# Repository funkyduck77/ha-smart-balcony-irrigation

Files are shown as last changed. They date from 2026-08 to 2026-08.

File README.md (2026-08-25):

# 🌱 Home Assistant Balkon-Bewässerungssystem

Ein intelligentes, vollautomatisiertes und ausfallsicheres Bewässerungssystem für den Balkon. Vollständig integriert in Home Assistant mit dynamischer Füllstandsberechnung, mehreren Fallback-Ebenen (Watchdogs) und individueller Gießlogik für bis zu 5 Pflanzen (Slots).

## 💡 Key Features
- **Brutto vs. Netto Füllstandsberechnung:** Striktes Trennen von physischem Wasser und nutzbarem Wasser (Totvolumen der Pumpe).
- **Hybrid-Steuerung:** Gießen nach Uhrzeit (oder Sonnenauf-/untergang) in Kombination mit echter Bodenfeuchte.
- **Untersetzer-Modus vs. Tröpfchen:** Intelligente Sperrzeiten nach dem Fluten des Untersetzers (inkl. Hitze-Bypass) oder Sickerpausen beim Gießen von oben.
- **Multi-Level Watchdogs:** Hardware-Trockenlaufschutz via aktiver Strommessung und dynamische Laufzeitlimits.
- **Smartes Logbuch:** Zeichnet jeden Gießvorgang inkl. Dauer, Verbrauch und Art (Manuell/Automatisch) auf.

---

## 📸 Screenshots & Dashboard

### Hauptansichten
*Das Responsive 2-Spalten-Layout auf dem Desktop.*
<br>
[Dashboard Hauptansicht](https://github.com/user-attachments/assets/e46ffc9e-1050-4b72-8b72-4a37b806c261)

*Die optimierte 1-Spalten-Ansicht für mobile Endgeräte.*
<br>
[Dashboard Mobile](https://github.com/user-attachments/assets/5ae38f84-7e9f-45ac-9b3f-b62c335ae683)

### Konfiguration
*Zentrale Konfiguration für Wasserfass und Watchdogs.*
<br>
[Globale Einstellungen](https://github.com/user-attachments/assets/2fc29b8b-f593-4bb9-b03f-c58f92324a54)

*Zentrale Vergabe der Pflanzennamen in den globalen Einstellungen.*
<br>
[Pflanzennamen Setup](https://github.com/user-attachments/assets/1ad855d4-3897-4641-916f-8dc4160eff52)

### Feinjustierung der Pflanzen
*Beispiel: Klassisches Gießen mit Start-/Zielwert und Sickerpausen.*
<br>
[Feinjustierung Tröpfchen](https://github.com/user-attachments/assets/3833a239-f6f6-4e24-8c0a-7977c8816305)

*Beispiel: Untersetzer-Modus mit langer Sperrzeit nach dem Fluten.*
<br>
[Feinjustierung Untersetzer](https://github.com/user-attachments/assets/ca4b359d-ce65-41ae-a133-8690ff3e2794)

*Steuerung nach Uhrzeit und das Notfall-Setup.*
<br>
[Uhrzeitsteuerung & Notfall](https://github.com/user-attachments/assets/7c919bb4-a890-4a9a-9201-73c406db67ec)

*Dynamische Steuerung nach Sonnenstand und das Notfall-Setup.*
<br>
[Sonnensteuerung & Notfall](https://github.com/user-attachments/assets/6598a505-8b60-41e8-8f59-561ecc60e1ed)

### Tools
*Fass befüllen oder Wasserverbrauch manuell korrigieren.*
<br>
[Manuelle Korrektur](https://github.com/user-attachments/assets/e38ff588-c6be-460b-87ec-2e6eee3abf9b)

### System
*Manuelle Kontrolle aller Hardware-Komponenten (Pumpe, Ventile & Trockenlaufschutz).*
<br>
[System-Übersicht](https://github.com/user-attachments/assets/c0530f64-9929-4684-b313-7d23d404d7c2)

### Historie
*Smartes Logbuch mit Historie über Dauer, Verbrauch und Liter pro Stunde (L/h).*
<br>
[Logbuch](https://github.com/user-attachments/assets/27954695-1dcf-47cf-ad8b-151f54cea6f6)

---

## 🛡️ Sicherheitskonzept (Die Watchdogs)

Da Wasserschäden auf Balkonen gelinde gesagt ungünstig sind und Pumpen nicht trockenlaufen oder gegen große Widerstände arbeiten dürfen, verfügt das System über fünf redundante Sicherheitsmechanismen. Fällt eine Ebene aus, greift sofort die nächste:

**1. Füllstandschutz (Software-Trockenlaufschutz)**
Das System berechnet kontinuierlich das verbleibende Wasser im Fass über Gießzeit und angegebenen Durchfluss. Erreicht dieser berechnete Wert das von dir in den globalen Einstellungen definierte "Totvolumen" (die Menge an Wasser, die nicht angesaugt werden kann, plus die Wasserverdrängung der Pumpe selbst), wird die Pumpe softwareseitig blockiert. Das verhindert, dass sie bei leerem Fass anläuft.

**2. Hardware-Trockenlaufschutz (Aktive Strommessung)**
Sollte der berechnete Wasserstand falsch sein (z. B. durch manuelle Entnahme mit der Gießkanne), greift diese physische Absicherung. Die smarte Steckdose überwacht den Stromverbrauch der Pumpe in Echtzeit. Zieht die Pumpe plötzlich weniger als 150 Watt Leistung, bedeutet das: Sie pumpt keinen Widerstand (Wasser) mehr, sondern zieht Luft. Das System blockiert die Pumpe innerhalb von Sekunden. 

**3. Dynamischer Laufzeit-Watchdog (Smartes Zeitlimit)**
Diese Funktion verhindert Überschwemmungen bei einem fehlerhaften Ablauf. Da das System die Ventile immer brav nacheinander gießt (Queued-Modus), prüft es bei jedem Start, welches Ventil gerade öffnet. Es nimmt die für genau diesen Slot geplante Gießdauer und addiert pauschal 2 Minuten als Sicherheitspuffer. Läuft die Pumpe bei diesem einen Durchgang unvorhergesehen länger als dieser errechnete Wert, kappt der Watchdog den Strom.

**4. Ghost-Prevention (Pumpen-Schutz)**
Wenn die Pumpe anspringt – sei es durch einen Glitch oder manuelles Schalten der Steckdose – ohne dass ein Ventil geöffnet ist, pumpt sie massiv gegen eine geschlossene Wand. Dies kann die Pumpe schwer beschädigen. Die Ghost-Prevention prüft sofort: *„Pumpe ist AN, aber alle Ventile sind ZU?“* und blockiert die Pumpe augenblicklich.

**5. Hard-Watchdog (Der absolute Not-Aus)**
Die letzte Fail-Safe-Ebene, falls alle anderen Skripte versagen sollten. Im Dashboard definierst du eine absolute Maximalzeit für den Dauerbetrieb der Pumpe. **Wichtig:** Dieser Wert muss mindestens 1 Minute höher eingestellt sein als deine längste Einzel-Gießlaufzeit! Überschreitet die Laufzeit diesen Wert, wird die Pumpe gnadenlos zwangsabgeschaltet.

---

## 🛠️ Stückliste (Hardware & Komponenten)

**Steuerung & Elektronik:**
- **Zentrale:** Home Assistant (inkl. HACS)
- **Ventil-Steuerung (Microcontroller):** ESP32 NodeMCU mit Terminalboard
- **Klima-Sensor (Hitze-Bypass):** IKEA TIMMERFLOTTE Temperatur-/Feuchtigkeitssensor smart
- **Bodenfeuchtesensoren:** 5x Ecowitt GW1100A Soil Moisture Sensoren
- **Pumpen-Steuerung:** IKEA TOFSMYGGA Steckdose für draußen (smart)
- **Netzteil (12V):** Schaltnetzteil 230V auf DC 12V 20A LED Transformator (240W)
- **Spannungswandler (für ESP32):** AC/DC 12V/24V zu DC 5V 5A 25W Wandler
- **Gehäuselüfter 40 mm 5V:** 2x optional, sollte auch ohne funktionieren. 

**Wasser & Gehäuse:**
- **Gehäuse:** Eurobox System Box Vollwand 40x30x12 cm, Grau inkl. Deckel
- **Wassertank:** 60 Liter Wasserfass
- **Pumpe:** T.I.P. Deep Inox (DIO) 45/13 (4-Zoll Tiefbrunnenpumpe)
- **Ventile:** 5x G1/4" elektronisches Magnetventil 12V (Funduino) für die Zonen (`switch.ventil_slot_1` bis `5`)
- **Schläuche & Tropfer:** Gardena Micro-Drip-System Tropfbewässerung Set Balkon
- **Gardena Adapter (statt Basisgerät):** Gardena Profi-System-Gerätestück 26,5 mm (G 3/4) & Gardena Hahn-Anschluss 4,6 mm (3/16")
- **Fittings (Verteiler):** 1/4" Wasserzulaufleitung Fitting Set (T + Y + I + L Typ)

---
 
### 💡 Alternative: Direkter Hausanschluss
Wenn du einen festen Wasseranschluss (Wasserhahn) auf dem Balkon hast, kannst du das Manifold auch direkt an die Hausleitung anschließen und dir das Wasserfass sowie die Pumpe sparen. 

*Der Anschluss auf diese Weise erfolgt auf eigene Verantwortung, da ich diese Anschlussmöglichkeit nicht getestet habe.*

**Wichtige Hinweise für diese Variante:**
- **Druckminderer (Zwingend erforderlich):** Ein Hausanschluss hat oft bis zu 4 Bar Druck. Du musst zwingend das klassische **Gardena Basisgerät 1000 oder 2000 (reduziert den Druck auf ca. 1,5 Bar)** *vor* das Manifold setzen, da sonst die Micro-Drip-Schläuche abplatzen. (Die 3D-Druckdatei für den speziellen Halter des Basisgerätes liegt den Druckdateien bei!).
- **Hauptventil (Optional, aber empfohlen):** Es wird empfohlen, den Hausanschluss nicht 24/7 unter Druck stehen zu lassen. Ein smartes Hauptventil (z. B. ein über Home Assistant steuerbares Magnetventil oder ein Zigbee-Bewässerungscomputer am Hahn) bringt zusätzliche Sicherheit vor Wasserschäden. 
- **Keine Code-Änderung nötig:** Die Logik ist bereits ab Werk für Hauptventile optimiert. Das System öffnet bei einem Gießvorgang *immer* erst das kleine Zonen-Ventil und schaltet 2 Sekunden später den Druck (die Pumpe / das Hauptventil) ein. Trage in der Installationstabelle einfach die Entität deines smarten Hauptventils bei `switch.pumpe_steckdose` ein.

---

## 📸 Aufbau & 3D-Druckteile

Damit die Elektronik und die Wasserverteilung (das Manifold) sicher und aufgeräumt untergebracht sind, ist das gesamte System in einer wetterfesten Eurobox verbaut. 

**🖨️ 3D-Druckdateien:**
Wenn du das System nachbauen möchtest, findest du alle von mir konstruierten Halterungen (für die Ventile, den ESP32 etc.) als fertige `.3mf`-Dateien direkt hier im Repository im Ordner [`/3d_druck`](./3d_druck).

**Bilder aus der Praxis:**
Hier siehst du, wie das Manifold (aus den 1/4" Fittings und Gardena-Adaptern) und die Elektronik im Gehäuse platziert wurden *(Bilder zum Vergrößern anklicken)*:

*Innenansicht der Eurobox / Manifold*
<br>
<a href="https://github.com/user-attachments/assets/c024af20-4ca3-4c12-9047-9c8ef93392bd">Innenansicht der Eurobox / Manifold</a>

*Ansicht Gehäuse unten*
<br>
<a href="https://github.com/user-attachments/assets/5b90ca3e-2273-432b-ac41-ec83036b4ba6">Ansicht Gehäuse unten</a>

*Ansicht Gehäuse oben*
<br>
<a href="https://github.com/user-attachments/assets/c7473101-2318-4e1d-9d1b-5fa6da537081">Ansicht Gehäuse oben</a>

*Ansicht Gehäuse geschlossen mit Kabelabdeckung*
<br>
<a href="https://github.com/user-attachments/assets/531e56e9-afdc-4778-a1e9-e41031fd6329">Ansicht Gehäuse geschlossen mit Kabelabdeckung</a>

---

## 💻 Voraussetzungen & Software

- **Zentrale:** Home Assistant
- **HACS Frontend-Erweiterungen (Zwingend!):** Bitte suche und installiere folgende Karten über den Home Assistant Community Store (HACS), damit das Dashboard korrekt angezeigt wird:
  - `layout-card` (für das Responsive Grid-Layout)
  - `fluid-level-background-card` (für die animierte Wassertank-Anzeige)
  - `config-template-card`
  - `fold-entity-row` (für die aufklappbaren Menüs)
  - `template-entity-row`
  - `card-mod` (für dynamische CSS-Anpassungen, wie Farbwechsel bei leerem Tank)

---

## 🎛️ Dokumentation der Einstellungsmöglichkeiten

Das Dashboard bietet vollständige Kontrolle über das System, ohne jemals den Code anfassen zu müssen.

### Konfiguration
- **Fass Volumen (Max) & Totvolumen:** Definiert die Brutto/Netto-Mathematik des Fasses. Die Pumpe stoppt zwingend beim Erreichen des Totvolumens.
- **Wasserpuffer:** Warnschwelle (Vorwarnung), bevor das Totvolumen erreicht wird.
- **Watchdog / Hitze-Schwelle:** Definiere globale Limits für den Not-Aus und die Außentemperatur, ab der sich Sperrzeiten im Untersetzer-Modus automatisch verkürzen.
- **Zuweisung der Pflanzennamen:** Zentrale Namensvergabe. Die hier eingetragenen Namen werden automatisch im gesamten System (Dashboards, Ventile, Logbuch) übernommen.

### Feinjustierung der Pflanzen
Für jeden der 5 Slots lässt sich die Gießlogik separat definieren:
- **Untersetzer-Modus AUS:** Ideal für Tröpfchenbewässerung von oben. Du definierst einen Startwert (Min) und Zielwert (Max). Das System gießt in "Dauer Normal"-Impulsen und wartet dazwischen die "Sickerpause" ab, bis der Zielwert erreicht ist.
- **Untersetzer-Modus AN:** Ideal zum Fluten von Untersetzern. Das System flutet einmalig (Dauer Normal) und blockiert den Slot danach für die "Sperrzeit (h)", damit die Pflanze das Wasser aufsaugen kann.
- **Durchfluss (L/h):** Der Durchfluss des jeweiligen Strangs. Dient zur exakten mathematischen Berechnung des Wasserverbrauchs für das Logbuch und die Restwasser-Anzeige.
- **Sonne statt Uhrzeit AUS:** Gießfreigabe über feste Start- und Endzeiten.
- **Sonne statt Uhrzeit AN:** Gießfreigabe dynamisch nach Sonnenstand, justierbar über "Minuten nach Aufgang" und "Minuten vor Untergang".
- **Notfall-Setup:** Fällt die Bodenfeuchtigkeit unter das "Notfall-Limit", ignoriert das System sämtliche Uhrzeiten oder Sonnenstände und feuert sofort einen Impuls in Höhe der "Dauer Notfall" ab. Danach greift eine separate "Notfall-Sperrzeit".

### Tools
- **Manuelle Korrektur:** Wurde Wasser entnommen (z.B. Gießkanne), kann der berechnete Wasserverbrauch überschrieben werden. Bei einem frisch befüllten Fass genügt ein Klick auf "Wasserfass befüllt (RESET)".

### System
- **Hardware & Ventile:** Direkter Zugriff auf alle Relais. Schaltest du hier manuell, greift die "Ghost-Prevention" dennoch ein, falls du die Pumpe ohne offenes Ventil startest.

### Historie
- **Logbuch:** Smartes Logbuch, das jeden Gießvorgang inkl. Dauer, Verbrauch und Liter pro Stunde (L/h) lückenlos dokumentiert.

---

## 🚀 Installation & Setup

1. **Abhängigkeiten installieren:** Stelle sicher, dass alle oben genannten HACS-Karten installiert sind.
2. **YAML-Dateien einfügen:** Kopiere die bereitgestellten Hauptdateien (`automations.yaml`, `scripts.yaml`, `template.yaml`) sowie den kompletten Ordner `helpers` (inklusive der 4 darin liegenden Dateien) in deine eigene Home Assistant Konfiguration. 
3. **Dashboard anlegen:** Erstelle ein neues Dashboard und füge den Code aus `dashboard.yaml` über den Raw-Konfigurationseditor ein.
4. **⚠️ WICHTIG: Eigene Entitäten eintragen (Pflicht!)**
   Damit das System in deinem Home Assistant funktioniert, musst du die neutralen Platzhalter im Code durch deine tatsächlichen Entitäten ersetzen. Suche in den heruntergeladenen Dateien nach folgenden Platzhaltern und passe sie an:

| Neutraler Platzhalter im Code | Beschreibung / Deine Hardware | Betroffene Dateien |
| :--- | :--- | :--- |
| `switch.pumpe_steckdose` | Die smarte Steckdose/Relais deiner Pumpe | `dashboard.yaml`, `automations.yaml`, `scripts.yaml` |
| `sensor.pumpe_leistung` | Der Stromverbrauchssensor (W) deiner Pumpe | `automations.yaml` |
| `switch.ventil_slot_1` (bis `5`) | Die Relais/Ventile für Slot 1 bis 5 | `dashboard.yaml`, `automations.yaml`, `scripts.yaml`, `template.yaml` |
| `sensor.bodenfeuchte_slot_1` (bis `5`) | Deine Bodenfeuchtigkeitssensoren (0-100%) | `dashboard.yaml`, `automations.yaml` |
| `sensor.aussentemperatur` | Ein lokaler Temperatursensor für den Hitze-Bypass | `automations.yaml`, `template.yaml` |
| `notify.smartphone` | Dein Notify-Dienst (z.B. `notify.mobile_app_iphone`) | `scripts.yaml` |
| `tts.sprachausgabe` | Dein Text-to-Speech Dienst (z.B. `tts.google_translate_say`) | `scripts.yaml` |
| `media_player.smart_speaker` | Dein Smart-Speaker für Warnungen (z.B. `media_player.wohnzimmer`) | `scripts.yaml` |

*(Tipp: Wenn du keine Sprachausgabe für Warnungen nutzen möchtest, kannst du den `tts.speak`-Block in der `scripts.yaml` einfach löschen).*

---

## ⚠️ Disclaimer (Haftungsausschluss)

**Wasser und Strom sind eine gefährliche Kombination!** Der Nachbau dieses Projekts erfolgt ausdrücklich auf eigene Gefahr. Bitte achte auf eine fachgerechte und wasserdichte Isolierung der Elektronik, sichere 230V-Komponenten ordnungsgemäß ab und nutze zwingend einen FI-Schutzschalter (RCD) für den Betrieb im Außenbereich.

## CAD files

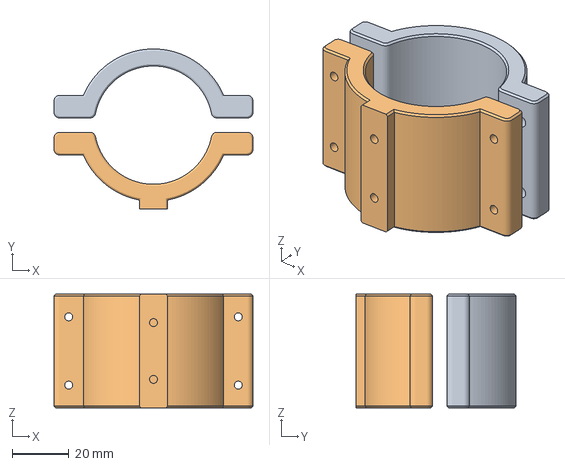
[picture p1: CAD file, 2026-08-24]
3d_druck/Halter Gardena Basisgerät 1000.3mf
70.0 x 56.3 x 40.0 mm
Körper2
Körper3

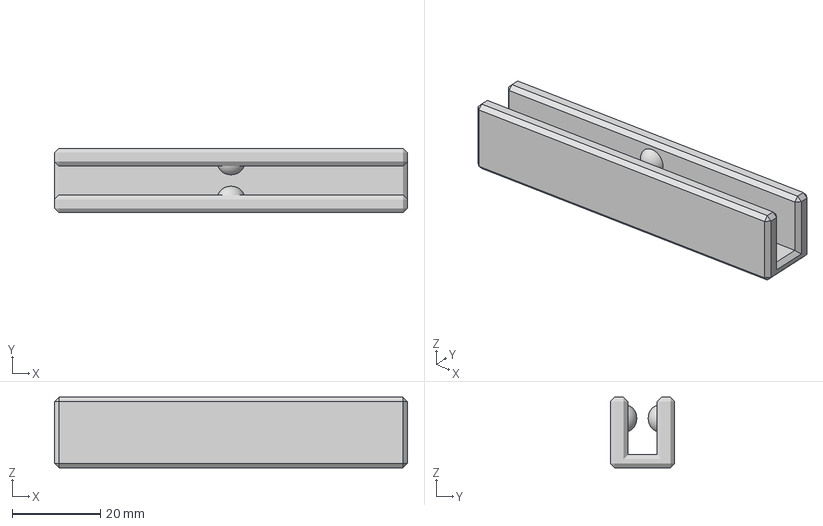
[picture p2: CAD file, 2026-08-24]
3d_druck/Verschlussclip Eurobox.3mf
80.0 x 14.6 x 16.0 mm

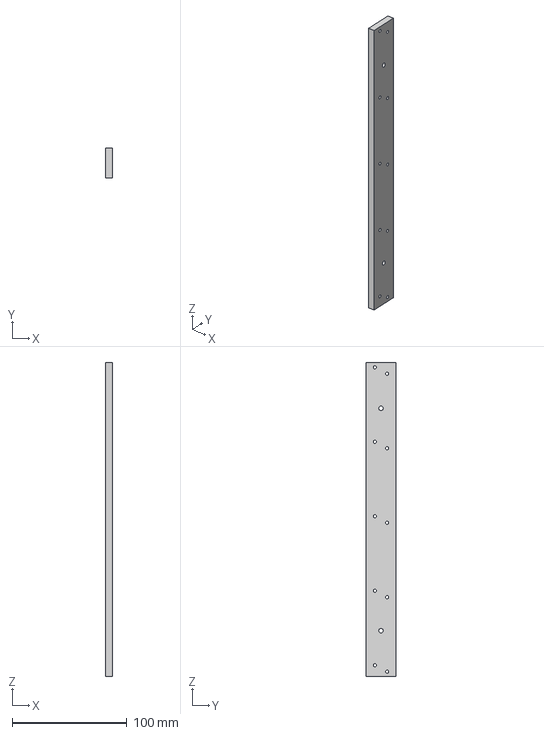
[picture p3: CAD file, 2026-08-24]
3d_druck/Manifold-Halter Gundplatte.3mf
6.00 x 26.6 x 274.0 mm

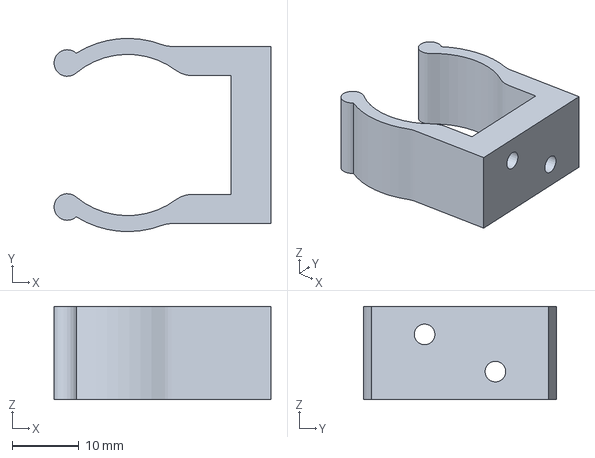
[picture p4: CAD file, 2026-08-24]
3d_druck/Manifold-Halter Ventilclip.3mf
32.6 x 29.0 x 14.0 mm

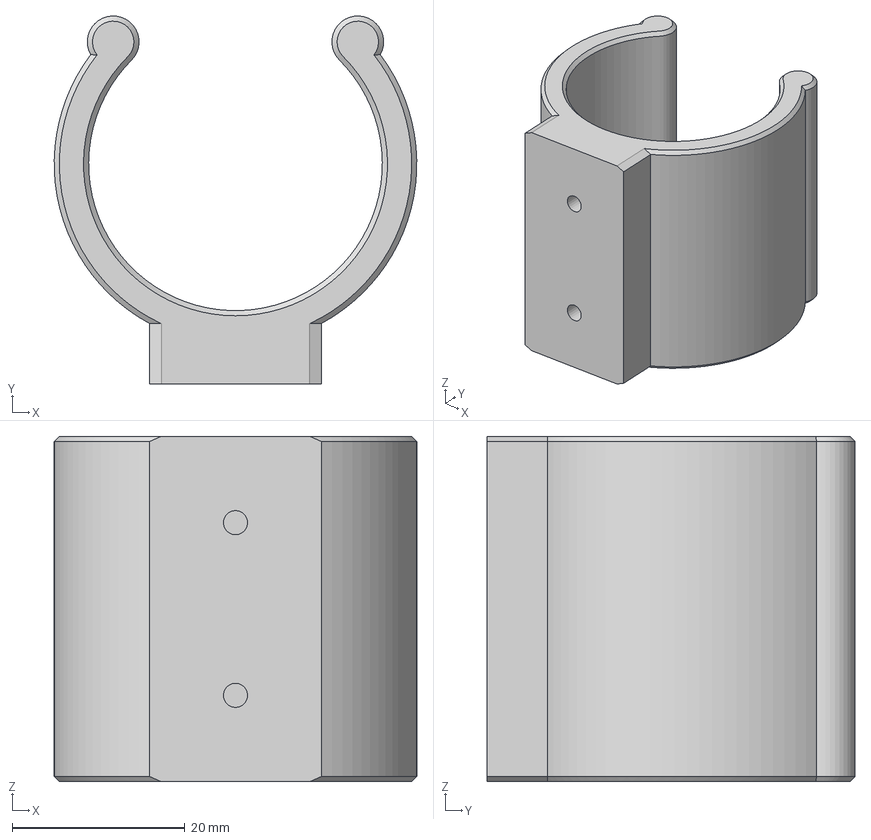
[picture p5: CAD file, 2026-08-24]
3d_druck/Clip Halter fuer Adapter Manifold - Pumpenschlauch.3mf
42.0 x 42.6 x 40.0 mm

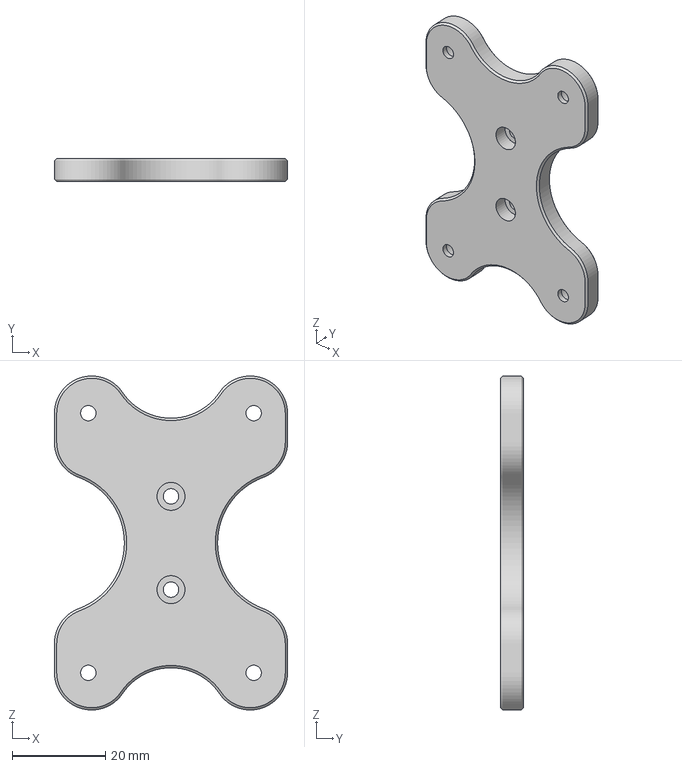
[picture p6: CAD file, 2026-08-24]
3d_druck/Grundplatte Halter fuer Adapter Manifold und Basisgerät - Pumpenschlauch.3mf
50.0 x 5.00 x 71.6 mm

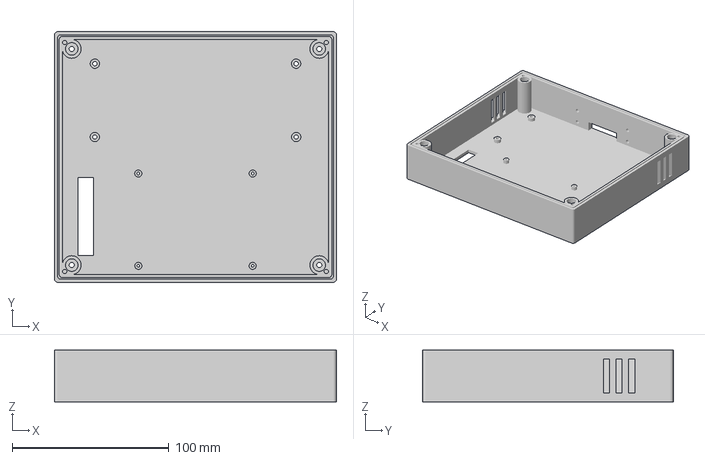
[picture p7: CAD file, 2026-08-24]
3d_druck/Gehaeuse_oben.3mf
180.0 x 160.0 x 33.0 mm

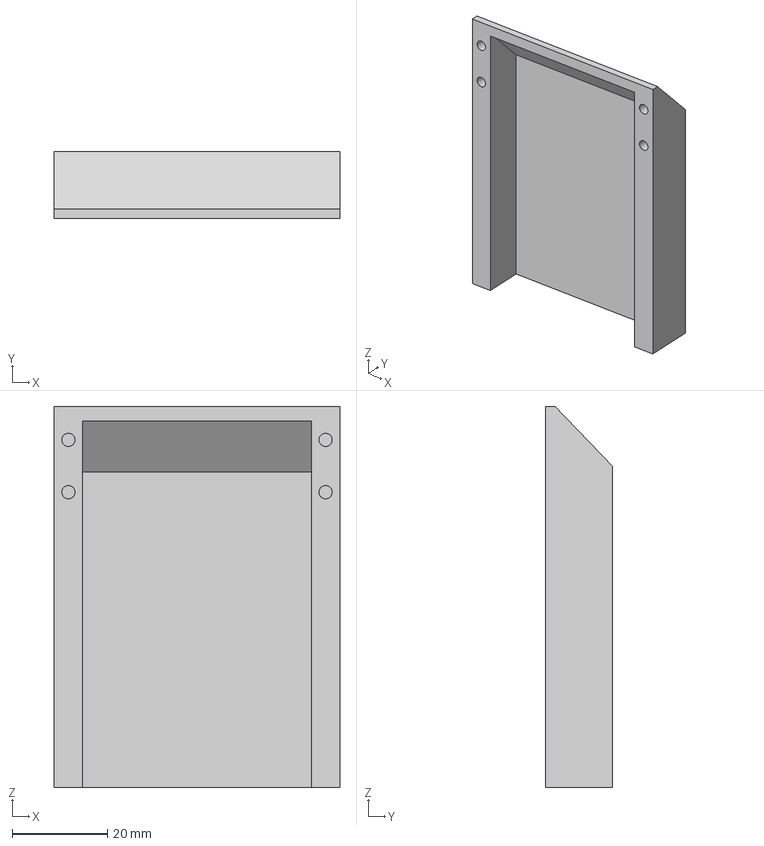
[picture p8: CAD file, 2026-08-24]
3d_druck/Kabelabdeckung.3mf
60.0 x 14.0 x 80.0 mm

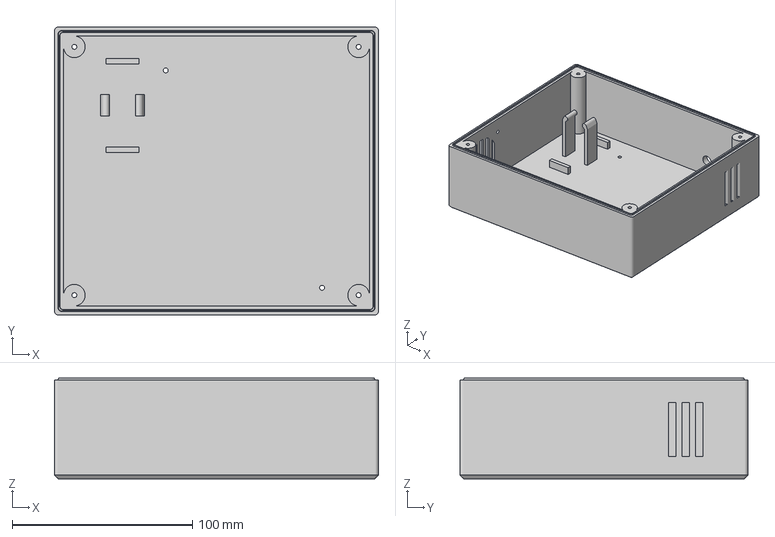
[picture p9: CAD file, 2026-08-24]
3d_druck/Gehaeuse_unten.3mf
180.0 x 160.0 x 55.9 mm

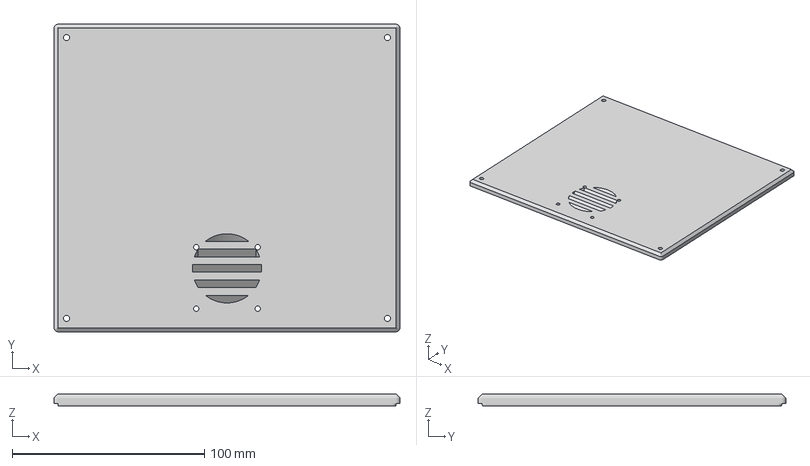
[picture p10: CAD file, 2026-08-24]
3d_druck/Deckel.3mf
180.0 x 160.0 x 6.20 mm

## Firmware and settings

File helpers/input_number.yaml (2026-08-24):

fass_volumen_max:
  name: "Wasserfass Volumen (Max)"
  min: 1
  max: 200
  step: 1
  unit_of_measurement: "L"
  icon: mdi:barrel
  mode: box
fass_totvolumen:
  name: "Totvolumen Pumpe"
  min: 0
  max: 50
  step: 0.5
  unit_of_measurement: "L"
  icon: mdi:water-minus
  mode: box
fass_warnpuffer:
  name: "Wasserpuffer (Stand niedrig)"
  min: 0
  max: 30
  step: 0.5
  unit_of_measurement: "L"
  icon: mdi:water-alert
  mode: box
wasserverbrauch_aktuell:
  name: "Wasserverbrauch Aktuell"
  min: 0
  max: 200.0
  step: 0.01
  unit_of_measurement: "L"
  mode: box
wasserverbrauch_korrektur:
  name: "Wasserverbrauch Korrektur"
  min: 0
  max: 200.0
  step: 0.1
  unit_of_measurement: "L"
  mode: box
pumpen_watchdog_minuten:
  name: "Pumpe-Not-Aus"
  min: 1
  max: 30
  step: 1
  unit_of_measurement: "min"
  icon: mdi:water-pump-off
  mode: box
sperrzeit_hitze_schwelle:
  name: "Hitze-Schwelle (°C)"
  min: 20
  max: 45
  step: 0.5
  unit_of_measurement: "°C"
  mode: box
  icon: mdi:thermometer-high
sperrzeit_hitze_max_h:
  name: "Hitze Sperrzeit-Limit"
  min: 1
  max: 120
  step: 1
  unit_of_measurement: "h"
  mode: box
  icon: mdi:timer-alert
maximale_giess_runden:
  name: "Max. Gieß-Runden"
  min: 1
  max: 20
  step: 1
  icon: mdi:refresh-circle
  mode: box

# --- SLOT 1 ---
slot_1_durchfluss:
  name: "Slot 1: Durchfluss"
  min: 1
  max: 50
  step: 1
  unit_of_measurement: "L/h"
  mode: box
  icon: mdi:water-pump
slot_1_feuchte_min:
  name: "Slot 1: Startwert (Min)"
  min: 0
  max: 100
  step: 1
  mode: box
  unit_of_measurement: "%"
  icon: mdi:water-alert
slot_1_feuchte_max:
  name: "Slot 1: Zielwert (Max)"
  min: 0
  max: 100
  step: 1
  mode: box
  unit_of_measurement: "%"
  icon: mdi:water-check
slot_1_feuchte_notfall:
  name: "Slot 1: Notfall-Limit"
  min: 0
  max: 100
  step: 1
  mode: box
  unit_of_measurement: "%"
  icon: mdi:alert-octagon
slot_1_impuls_dauer:
  name: "Slot 1: Dauer Normal"
  min: 1
  max: 15
  step: 1
  mode: box
  unit_of_measurement: "min"
  icon: mdi:timer-outline
slot_1_impuls_dauer_notfall:
  name: "Slot 1: Dauer Notfall"
  min: 1
  max: 30
  step: 1
  mode: box
  unit_of_measurement: "min"
  icon: mdi:timer-sand
slot_1_sicker_pause:
  name: "Slot 1: Sickerpause"
  min: 1
  max: 300
  step: 1
  mode: box
  unit_of_measurement: "min"
  icon: mdi:timer-sand
slot_1_sperrzeit_stunden:
  name: "Slot 1: Sperrzeit"
  min: 1
  max: 120
  step: 1
  mode: box
  unit_of_measurement: "h"
  icon: mdi:timer-lock
slot_1_sperrzeit_notfall_stunden:
  name: "Slot 1: Notfall-Sperrzeit"
  min: 1
  max: 48
  step: 1
  mode: box
  unit_of_measurement: "h"
  icon: mdi:timer-alert
slot_1_sonne_start_offset:
  name: "Slot 1: Min. nach Aufgang"
  min: 0
  max: 300
  step: 15
  mode: box
  unit_of_measurement: "min"
  icon: mdi:weather-sunset-up
slot_1_sonne_ende_offset:
  name: "Slot 1: Min. vor Untergang"
  min: 0
  max: 300
  step: 15
  mode: box
  unit_of_measurement: "min"
  icon: mdi:weather-sunset-down

# --- SLOT 2 ---
slot_2_durchfluss:
  name: "Slot 2: Durchfluss"
  min: 1
  max: 50
  step: 1
  unit_of_measurement: "L/h"
  mode: box
  icon: mdi:water-pump
slot_2_feuchte_min:
  name: "Slot 2: Startwert (Min)"
  min: 0
  max: 100
  step: 1
  mode: box
  unit_of_measurement: "%"
  icon: mdi:water-alert
slot_2_feuchte_max:
  name: "Slot 2: Zielwert (Max)"
  min: 0
  max: 100
  step: 1
  mode: box
  unit_of_measurement: "%"
  icon: mdi:water-check
slot_2_feuchte_notfall:
  name: "Slot 2: Notfall-Limit"
  min: 0
  max: 100
  step: 1
  mode: box
  unit_of_measurement: "%"
  icon: mdi:alert-octagon
slot_2_impuls_dauer:
  name: "Slot 2: Dauer Normal"
  min: 1
  max: 15
  step: 1
  mode: box
  unit_of_measurement: "min"
  icon: mdi:timer-outline
slot_2_impuls_dauer_notfall:
  name: "Slot 2: Dauer Notfall"
  min: 1
  max: 30
  step: 1
  mode: box
  unit_of_measurement: "min"
  icon: mdi:timer-sand
slot_2_sicker_pause:
  name: "Slot 2: Sickerpause"
  min: 1
  max: 300
  step: 1
  mode: box
  unit_of_measurement: "min"
  icon: mdi:timer-sand
slot_2_sperrzeit_stunden:
  name: "Slot 2: Sperrzeit"
  min: 1
  max: 120
  step: 1
  mode: box
  unit_of_measurement: "h"
  icon: mdi:timer-lock
slot_2_sperrzeit_notfall_stunden:
  name: "Slot 2: Notfall-Sperrzeit"
  min: 1
  max: 48
  step: 1
  mode: box
  unit_of_measurement: "h"
  icon: mdi:timer-alert
slot_2_sonne_start_offset:
  name: "Slot 2: Min. nach Aufgang"
  min: 0
  max: 300
  step: 15
  mode: box
  unit_of_measurement: "min"
  icon: mdi:weather-sunset-up
slot_2_sonne_ende_offset:
  name: "Slot 2: Min. vor Untergang"
  min: 0
  max: 300
  step: 15
  mode: box
  unit_of_measurement: "min"
  icon: mdi:weather-sunset-down
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

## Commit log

2026-08-24 Implement irrigation automation rules in automations.yaml
    Added multiple automation rules for irrigation system management, including moisture monitoring, pump safety, and notification actions.
2026-08-24 Add automation scripts for notifications and water control
    Added multiple automation scripts for notifications, water consumption management, and pump control.
2026-08-24 Add sensors and triggers for irrigation system
2026-08-24 Create input_datetime.yaml for time slot configuration
    Added time slots for five different windows with start and end times.
2026-08-24 Add water management parameters in input_number.yaml
    Added configuration for water management parameters including volume, consumption, and pump settings across multiple slots.
2026-08-24 Add 3d print files
    Add 3d print files for the housing
    [Deckel.3mf, Gehaeuse_oben.3mf, Gehaeuse_unten.3mf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]
2026-08-24 Add 3d print files
    3D files added for manifold-to-pump-hose adapter
    [Clip Halter fuer Adapter Manifold - Pumpenschlauch.3mf, Grundplatte Halter fuer Adapter Manifold - Pumpenschlauch.3mf]
2026-08-24 Add 3d print files
    Verschlussclip Eurobox
    Ventilhalter Grundplatte und Ventilclip
    [Manifold-Halter Gundplatte.3mf, Manifold-Halter Ventilclip.3mf, Verschlussclip Eurobox.3mf]
2026-08-24 Add 3d print files
    Halter für Gardena Basisgerät 1000
    [Halter Gardena Basisgerät 1000.3mf]
2026-08-24 Rename Grundplatte Halter fuer Adapter Manifold - Pumpenschlauch.3mf to Grundplatte Halter fuer Adapter Manifold und Basisgerät - Pumpenschlauch.3mf
    [Grundplatte Halter fuer Adapter Manifold und Basisgerät - Pumpenschlauch.3mf]
